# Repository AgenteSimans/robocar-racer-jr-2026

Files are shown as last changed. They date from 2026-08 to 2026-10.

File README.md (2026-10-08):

# 🏎️ Robocar Jr — Placa de Controle & Gerenciamento
### Robocar Race 2025 · hardware em KiCad 10

> Corpo de prova eletrônico de um carro autônomo de competição, projetado no **KiCad** para
> concentrar, em uma única placa, o cérebro (**ESP32‑DEVKITC**), o copiloto embarcado
> (**Raspberry Pi**), os sensores de navegação (**GY‑87**), a medição de energia (**ADS1115**)
> e toda a interface de potência dos atuadores (servo de direção + ESC/motor BLDC).

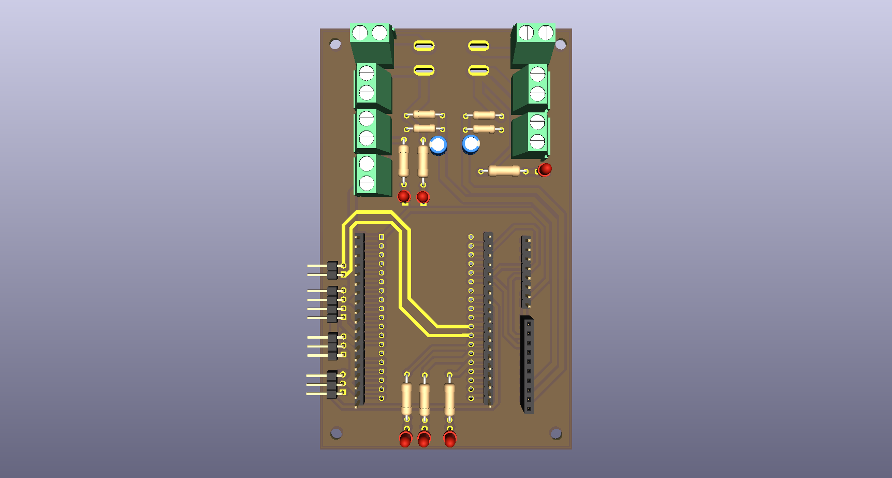
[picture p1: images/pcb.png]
Layout da PCB


<p align="center">
  
  
  
  
  
  
</p>

---

## ✨ O que a placa faz

| Bloco | Papel no veículo |
|---|---|
| 🧠 **ESP32‑DEVKITC** | Controlador em tempo real (sensores, PWM, decisão), montado em soquete. |
| 🍓 **Raspberry Pi** | Co‑processador de visão/navegação, ligado ao ESP32 por **UART** e alimentado via **USB‑C** na placa. |
| 🧭 **GY‑87 (IMU)** | Orientação e movimento — MPU6050 + HMC5883L + BMP280, em barramento I²C. |
| 📊 **ADS1115** | ADC externo de **16 bits** (I²C) com **4 canais** para medição precisa de bateria e dos rails de potência. |
| ⚡ **Gestão de energia** | Conversor **Buck** (+5 V) e conversor **Step‑up** (+8 V / +12 V) a partir da bateria, com chaves de comutação. |
| 🎯 **Atuadores** | Saída dedicada para **servo** (direção, 5 V) e para **ESC/motor BLDC** (tração, 12 V de potência + sinal 5 V). |
| 💡 **Feedback visual** | LEDs de estado (**Estado_1/2/3**) e LEDs de presença de tensão (**+BV**, **+12 V**). |
| 📡 **Enlace serial** | UART `TX/RX_RASPBERRY` para telemetria e troca de comandos ESP32 ↔ Raspberry. |
| 🎮 **Modo manual (opcional)** | Previsão de entradas de receptor RC (`Radio`, `Servo Rec`, `Motor Rec`). |

---

## ⚡ Arquitetura de potência

A bateria (`+BV`) é a fonte primária e é distribuída/comutada por **chaves DPST (SW1/SW2)**.
Dois estágios de conversão DC‑DC geram os rails usados pelo sistema:

| Rail | Gerado por | Alimenta |
|---|---|---|
| **+5 V** (`Buck_out`) | Conversor **Buck** (`Buck_in` → `Buck_out`) | Lógica de sinal, **servo motor**, barramento do enlace |
| **+3,3 V** | Regulação a partir de +5 V | **ESP32**, **GY‑87**, **ADS1115** |
| **+8 V** | Bateria 2S | Alimentação do Motor |
| **+12 V** | Bateria 3S | Alimentação do Esp32 e Raspberry  |
| **USB‑C 5 V** | Conector `Raspbery_usbc` | **Raspberry Pi** |

> O **servo** recebe potência e sinal em 5 V (conector `J3`); o **motor/ESC** recebe a
> potência de 12 V pelo conector `Motor in` (`J11`) e o sinal PWM de 5 V pelo conector `J4` —
> separando claramente o caminho de potência do caminho de controle.

---

## 📊 Monitoramento de bateria e de rails (ADS1115)

Quatro entradas analógicas, todas condicionadas por **divisores resistivos + filtro RC**,
lidas com resolução de 16 bits (muito mais estáveis que o ADC interno do ESP32):

| Canal | Origem medida | Sentido |
|:-----:|---|---|
| **A0** | Divisor de Tensão da Bateria 3S | Tensão da Bateria 3S |
| **A1** | Divisor de Tensão da Bateria 2S | Tensão da Bateria 2S |

Endereço I²C do ADS1115 com `ADDR` amarrado ao GND (**0x48**); `ALERT` usado conforme estratégia de firmware (polling ou interrupção).

---

## 🔗 Comunicação & interfaces

- **I²C (compartilhado):** `SDA` e `SCL` ligam **GY‑87** e **ADS1115** ao ESP32.
- **UART ↔ Raspberry:** pares `TX_RASPBERRY` / `RX_RASPBERRY` formam o enlace serial
  ESP32 ⇄ Raspberry (telemetria, comandos, handshake de missão).
- **Sinais de controle:** `Sinal_Servo` (direção) e `Sinal_Motor` (tração via ESC).
- **Feedback luminoso:** `Estado_1`, `Estado_2`, `Estado_3` (LEDs 3 mm, R = 220 Ω) indicam a
  fase/estado da máquina; LEDs adicionais sinalizam presença de **+BV** (R = 330 Ω) e **+12 V** (R = 1 kΩ).
- **Chaves:** `SW1`/`SW2` (DPST) para comutação/corte dos ramos de bateria e enlace.

---

## 🧱 Conectores de campo

| Ref. | Função | Sinais |
|---|---|---|
| **J7** | Módulo **GY‑87** | +3,3 V · SCL · SDA · GND |
| **J10** | Entrada do **Buck** | `Buck_in` · GND |
| **J11** | Potência do **motor** | +12 V (`Motor in`) · GND |
| **J3** | **Servo motor** | +5 V (`Buck_out`) · `Sinal_Servo` · GND |
| **J4** | Sinal do **ESC/motor** | +5 V · `Sinal_Motor` · GND |
| **J14** | **USB‑C do Raspberry** | +5 V · GND |
| **J15** | Saída do **Step‑up** | +12 V · GND |
| **J2 / J5** | Soquete / breakout **ESP32‑DEVKITC** | barramento completo do módulo |
| **SW1 / SW2** | Chaves DPST | comutação de bateria/enlace |

> A atribuição física de cada GPIO do ESP32 segue o soquete `J2`/`J5`; a referência canônica
> é o esquemático hierárquico incluído no projeto.

---

## 🖼️ Galeria

### Esquemático (hierárquico)
Blocos de baterias, entradas de motor/conversor Buck, barramento do Raspberry, conexões do
GY‑87, enlace serial, ADS1115, divisores de tensão e LEDs de feedback.

Esquemático

### Layout da PCB
Posicionamento dos conectores de bateria e de potência, soquete do ESP32, trilhas de 12 V /
5 V dimensionadas para corrente e separação cuidadosa entre potência e sinal.

PCB

---

## 📄 Licença & crédito

Hardware aberto sob licença **MIT** — use, estude e adapte como base para o seu Robocar Jr. 🏁

<sub>Projeto de competição · **Robocar Race 2025** · desenvolvido por **Pablo Nunes de Oliveira** · KiCad E.D.A. 10</sub>

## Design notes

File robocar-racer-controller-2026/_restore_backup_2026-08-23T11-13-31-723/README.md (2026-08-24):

# robocar-racer-controller-2025

## Visão Geral
Este repositório contém o projeto de hardware da **placa controladora** desenvolvida pela **Equipe Laser** para a competição **Robocar Racer 2025**. A placa recebe e interpreta dados da **Raspberry Pi** para controlar o motor brushless (ESC) e o servo motor, implementando isolamento galvânico e redundância via rádio controle.

---

## Visualização do Projeto

### Modelo 3D
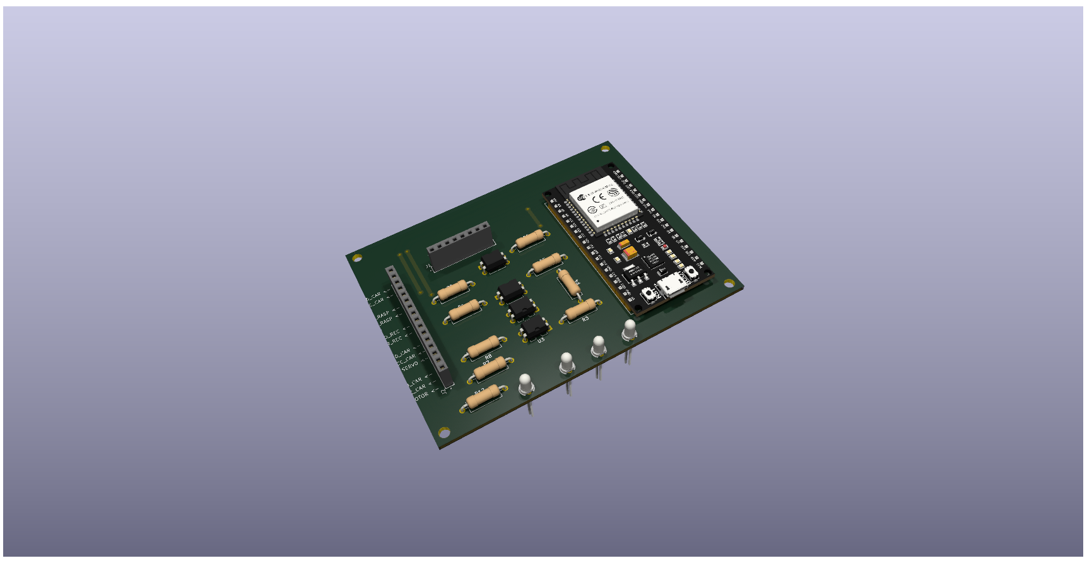
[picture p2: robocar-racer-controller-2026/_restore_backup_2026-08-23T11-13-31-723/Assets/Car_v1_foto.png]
Vista 3D da Controladora


### Documentação Técnica (PDF)
Para detalhes de roteamento e conexões, acesse os arquivos abaixo:
* [📄 Esquemático Completo](Assets/Esquemático.pdf)
* [📄 Layout da PCB](Assets/PCB_layout.pdf)

---

## Especificações Técnicas
* **Microcontrolador:** ESP32 (NodeMCU/DevKit V1)
* **Software de EDA:** KiCad 8.0.6
* **Dimensões da PCB:** 91.00 mm x 67.75 mm
* **Isolamento:** Optoacopladores **PC817** (Separação entre lógica/USB e potência/Bateria).

## Operação e Segurança
O sistema gerencia a tração e direção do veículo em três estados:
1. **Modo Autônomo:** Controle via Raspberry Pi (Serial/USB).
2. **Modo Manual (Radio):** Redundância via rádio controle externo (Fail-safe).
3. **Modo Neutro:** Veículo parado por segurança.

## Interfaces de Hardware
* **Barramento GY-87:** Conexão I2C para IMU (Telemetria e estabilização).
* **Feedback Visual:** 4 LEDs (Power, Estado 1, Estado 2, Estado 3).
* **Isolamento de Terra:** Separação física entre `GND_CAR` e `Earth` (GND lógico).

## Estrutura do Repositório
* **`/Gerber`**: Arquivos finais de fabricação e furação.
* **`/Assets`**: Fotos, modelos 3D e documentação técnica em PDF.
* **`/Meus footprints.pretty`**: Biblioteca de footprints personalizados.
* **`Car_v1.kicad_...`**: Arquivos fonte do projeto para edição no KiCad.

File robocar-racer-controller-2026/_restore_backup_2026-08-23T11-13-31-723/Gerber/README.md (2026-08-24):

# Arquivos de Fabricação (Gerber)

Estes ficheiros são os ativos finais necessários para a produção da PCB, seja via fabricação industrial (JLCPCB, PCBWay, etc.) ou fresagem CNC.

## Especificações para Fabricação

* **Formato:** Gerber RS-274X.
* **Furação:** Excellon Drill Files.
* **Camadas incluídas:**
    * Cobre (Top/Bottom)
    * Máscara de solda (Solder Mask)
    * Legenda/Serigrafia (Silkscreen)
    * Corte de borda (Edge Cuts)

## Instruções

Estes ficheiros foram gerados a partir do KiCad 8.0.6. Se for realizar a fresagem via CNC (ex: utilizando **FlatCAM**), utilize preferencialmente os ficheiros de isolamento gerados para as camadas de cobre.

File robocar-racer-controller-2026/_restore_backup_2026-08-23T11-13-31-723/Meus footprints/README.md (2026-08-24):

# Minha Biblioteca de Footprints Personalizada

Esta pasta contém a minha coleção de footprints desenvolvida para o projeto **Robocar Racer 2025** e outros componentes customizados.

## Sobre a Biblioteca
Esta é uma biblioteca autoral que reúne todos os modelos de componentes que eu desenvolvi ou modifiquei para garantir a precisão do hardware. Optei por incluir a biblioteca completa neste repositório para assegurar que todos os footprints utilizados no layout da PCB estejam disponíveis para consulta e edição.

### Destaques:
* **Módulos Integrados:** Footprints validados para ESP32, sensores e IMUs.
* **Otimização de Soldagem:** Pads ajustados para facilitar a montagem manual e garantir durabilidade.
* **Componentes Customizados:** Modelos criados do zero para componentes que não constam nas bibliotecas padrão do KiCad.

## Uso no Projeto
Para que o KiCad reconheça as peças corretamente ao abrir o arquivo `.kicad_pcb`:
1. Vá em **Preferences** > **Manage Footprint Libraries**.
2. Na aba **Project Specific Libraries**, adicione esta pasta (`Meus footprints.pretty`).

**Nota:** Por ser uma biblioteca completa, ela pode conter componentes adicionais que não estão em uso nesta versão específica da placa, mas que fazem parte do meu fluxo de design.

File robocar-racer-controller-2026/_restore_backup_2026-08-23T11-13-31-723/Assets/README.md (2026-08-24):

# Assets do Projeto

Esta pasta contém os recursos visuais e a documentação técnica exportada para consulta rápida.

## Conteúdo

* **Imagens:**
    * `Car_v1_foto_da_PCB.png`: Renderização 3D da placa para visualização de componentes.
* **Documentação (PDF):**
    * `Esquemático.pdf`: Diagrama elétrico completo do sistema.
    * `PCB_layout.pdf`: Desenho das trilhas, planos de terra e camadas de montagem.

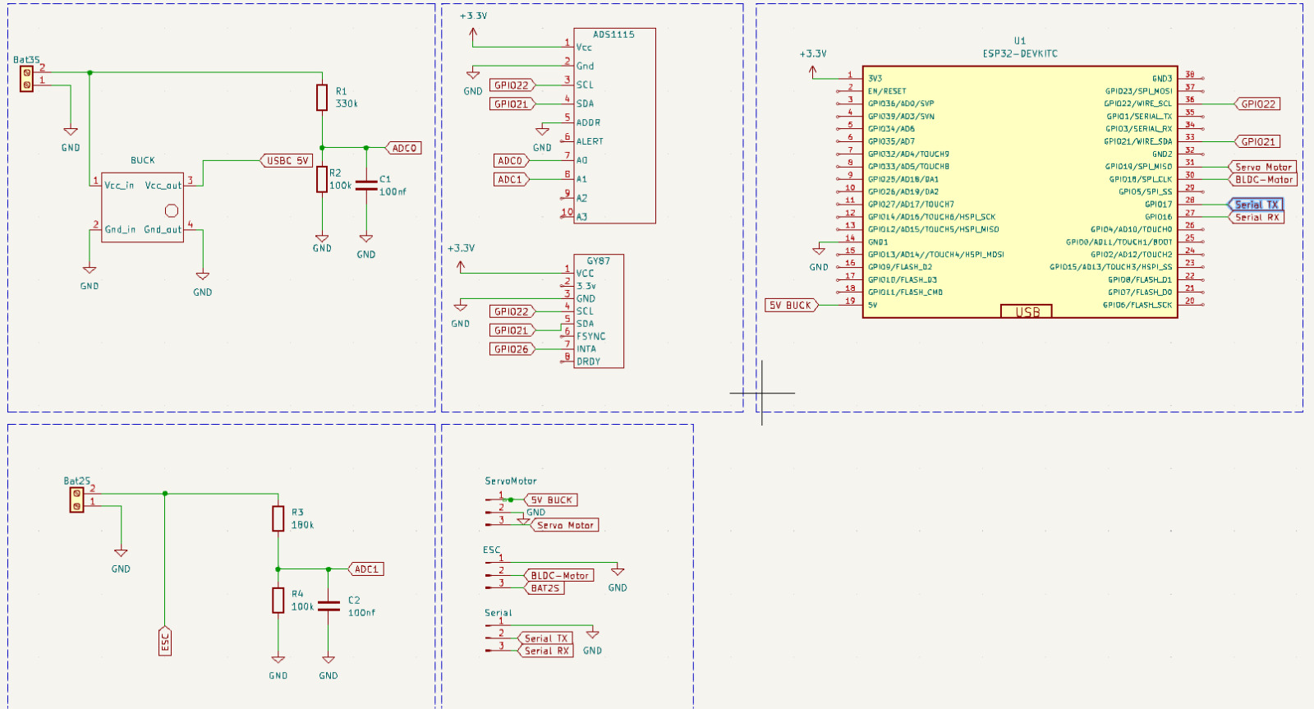
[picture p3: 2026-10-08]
images/esquematico.jpeg

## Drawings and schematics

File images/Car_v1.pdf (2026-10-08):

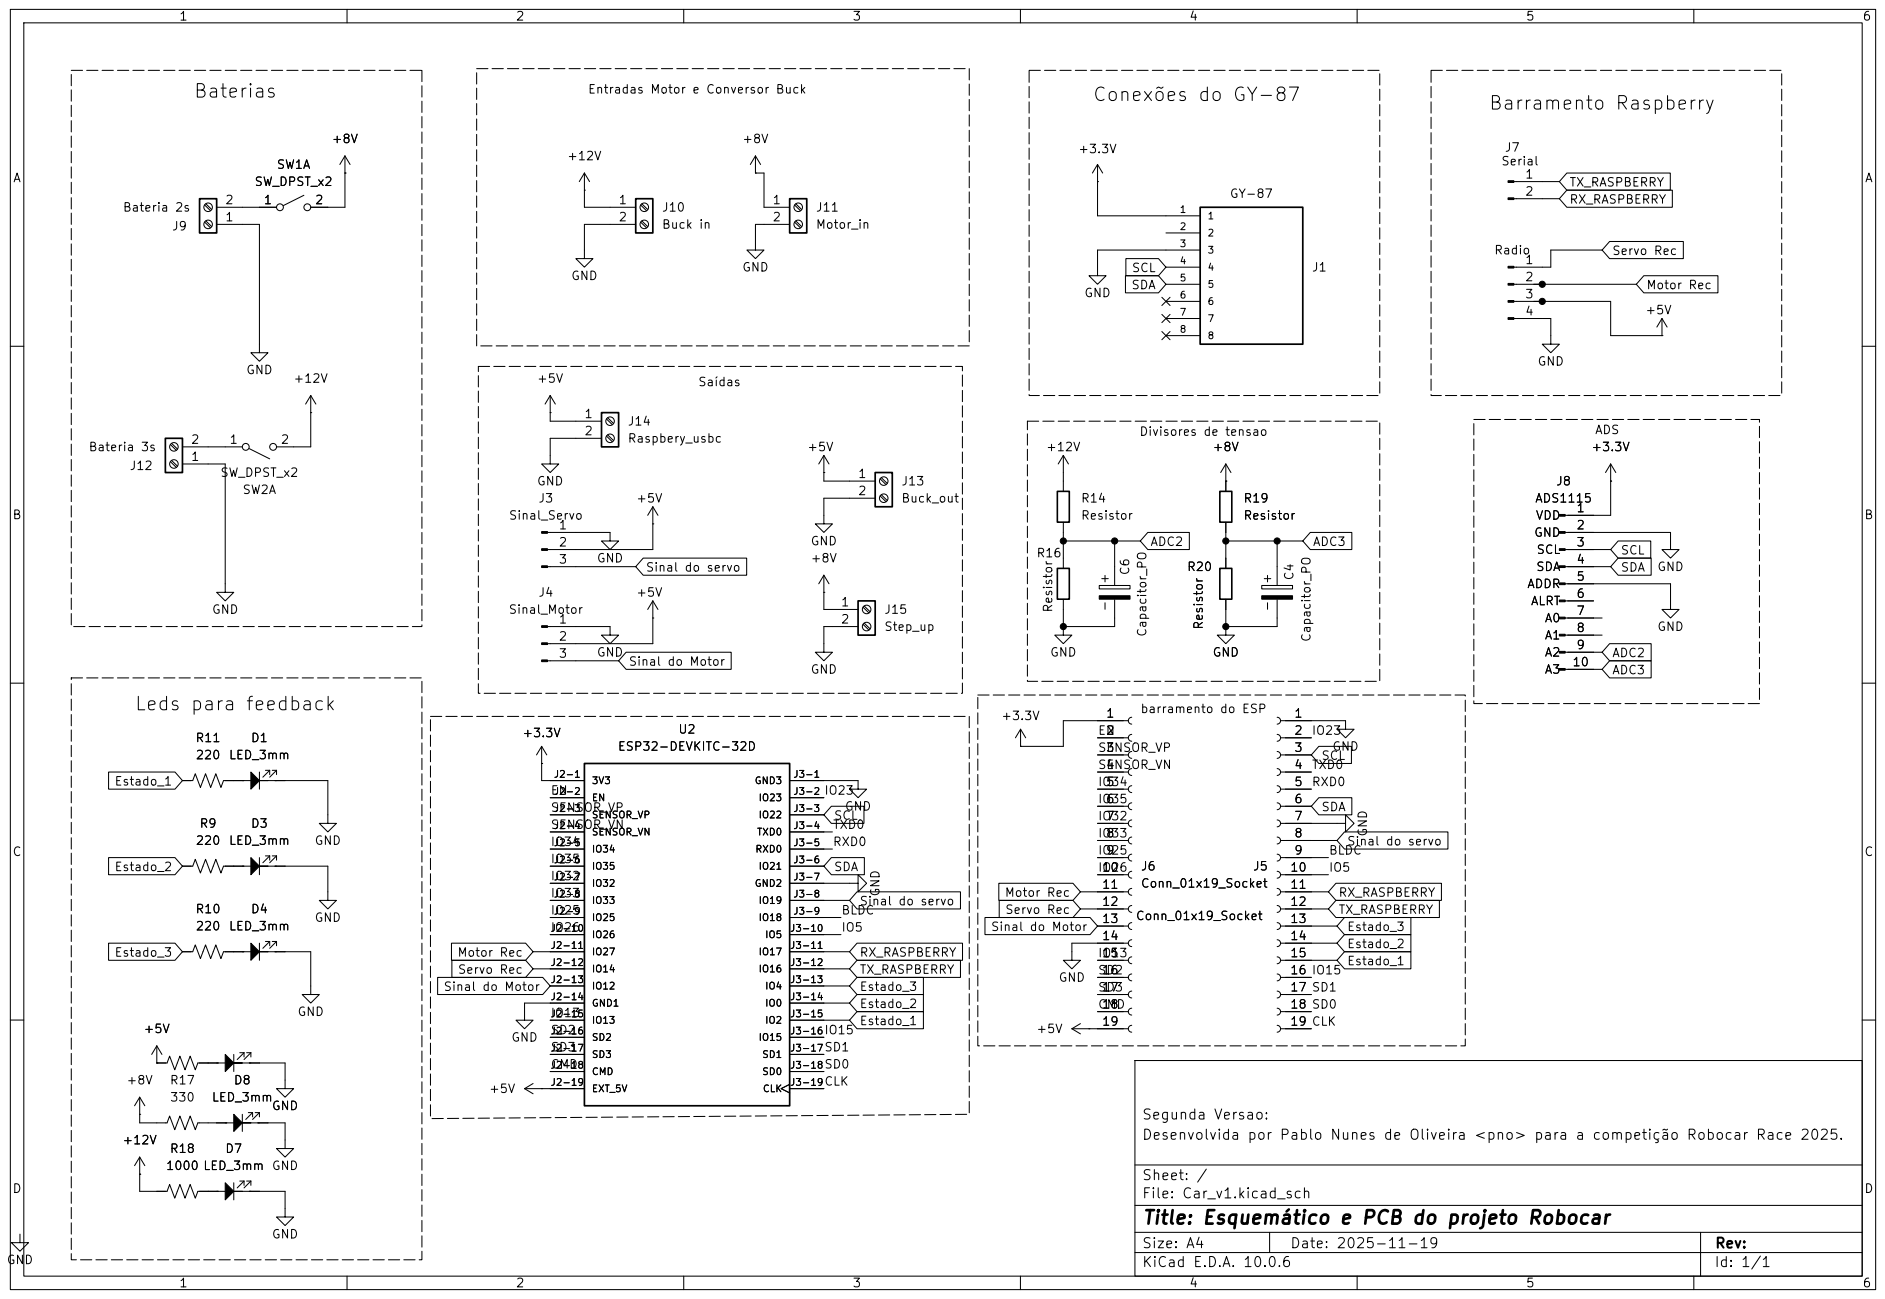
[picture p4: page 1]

Saídas Entradas Motor e Conversor Buck U2

Segunda Versao:
Desenvolvida por Pablo Nunes de Oliveira <pno> para a competição Robocar Race 2025.

Sheet: /
File: Car_v1.kicad_sch
Title: Esquemático e PCB do projeto Robocar

Size: A4 | Rev:
KiCad E.D.A. 10.0.6 | Id: 1/1

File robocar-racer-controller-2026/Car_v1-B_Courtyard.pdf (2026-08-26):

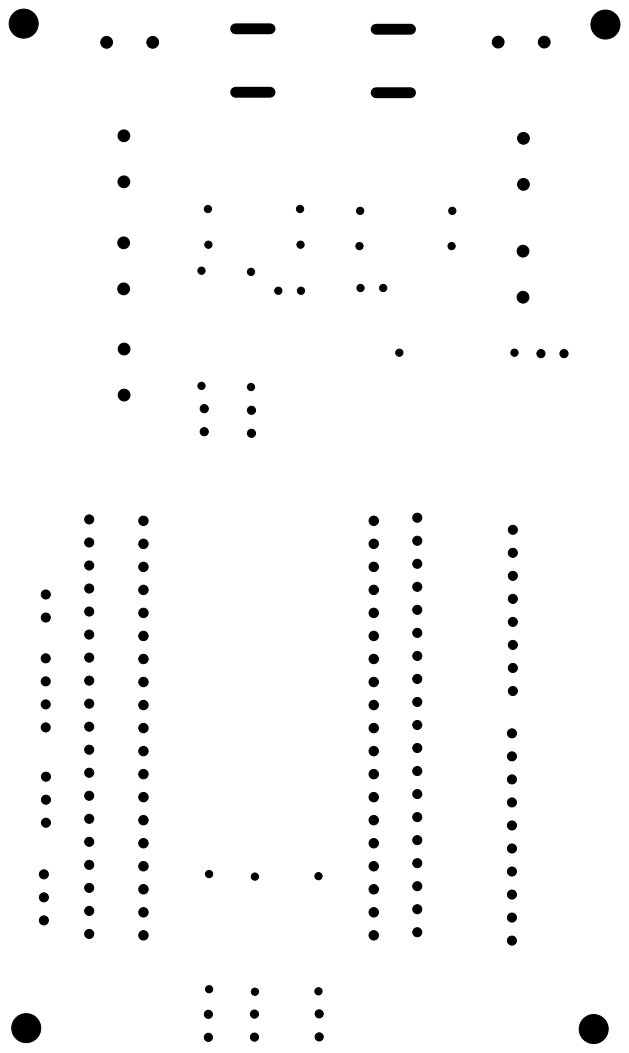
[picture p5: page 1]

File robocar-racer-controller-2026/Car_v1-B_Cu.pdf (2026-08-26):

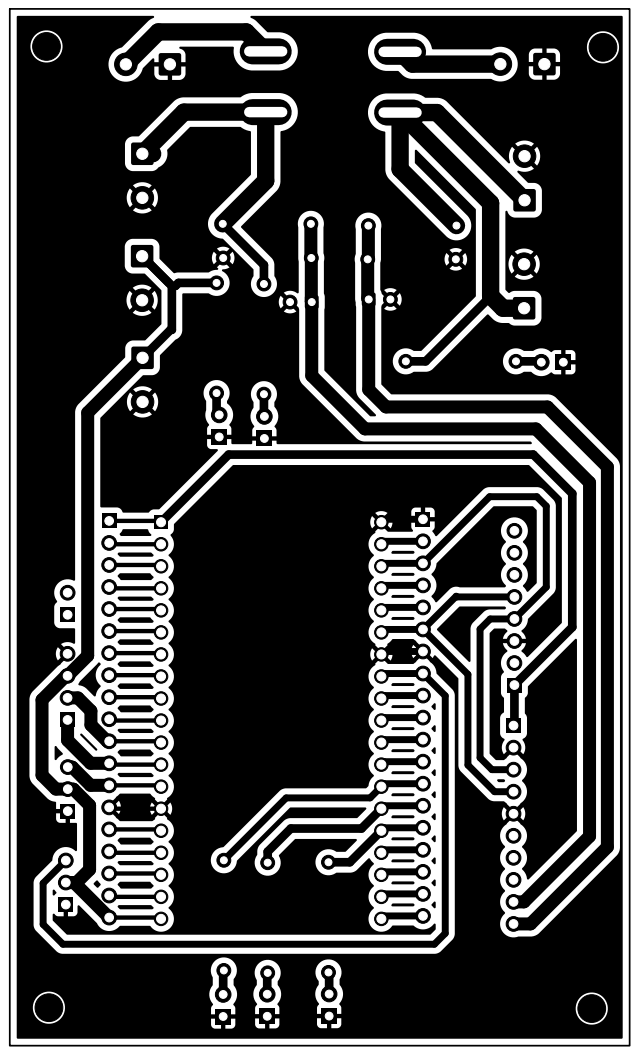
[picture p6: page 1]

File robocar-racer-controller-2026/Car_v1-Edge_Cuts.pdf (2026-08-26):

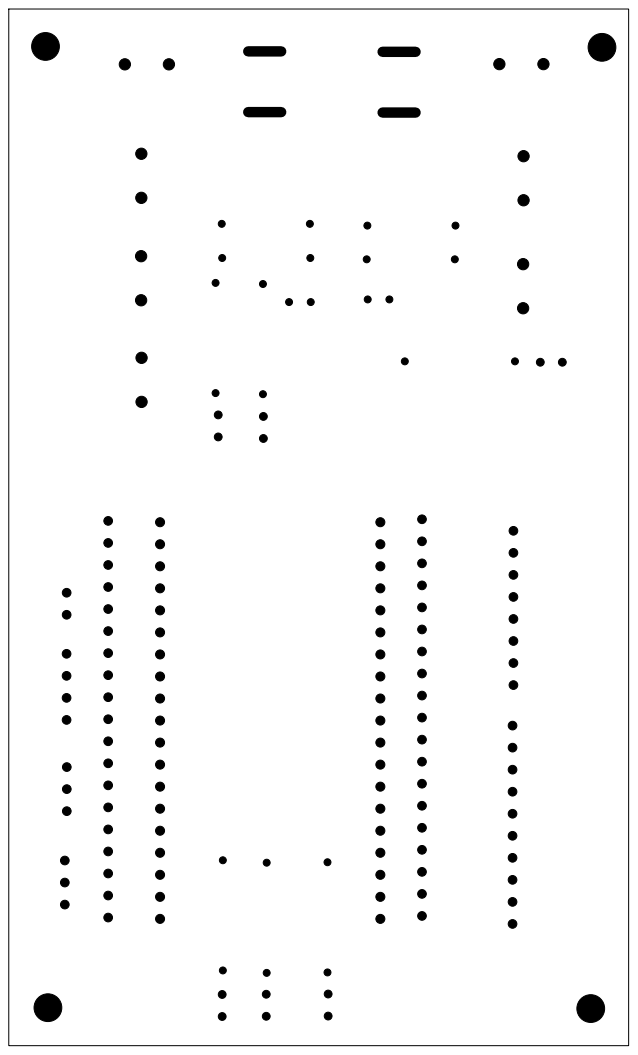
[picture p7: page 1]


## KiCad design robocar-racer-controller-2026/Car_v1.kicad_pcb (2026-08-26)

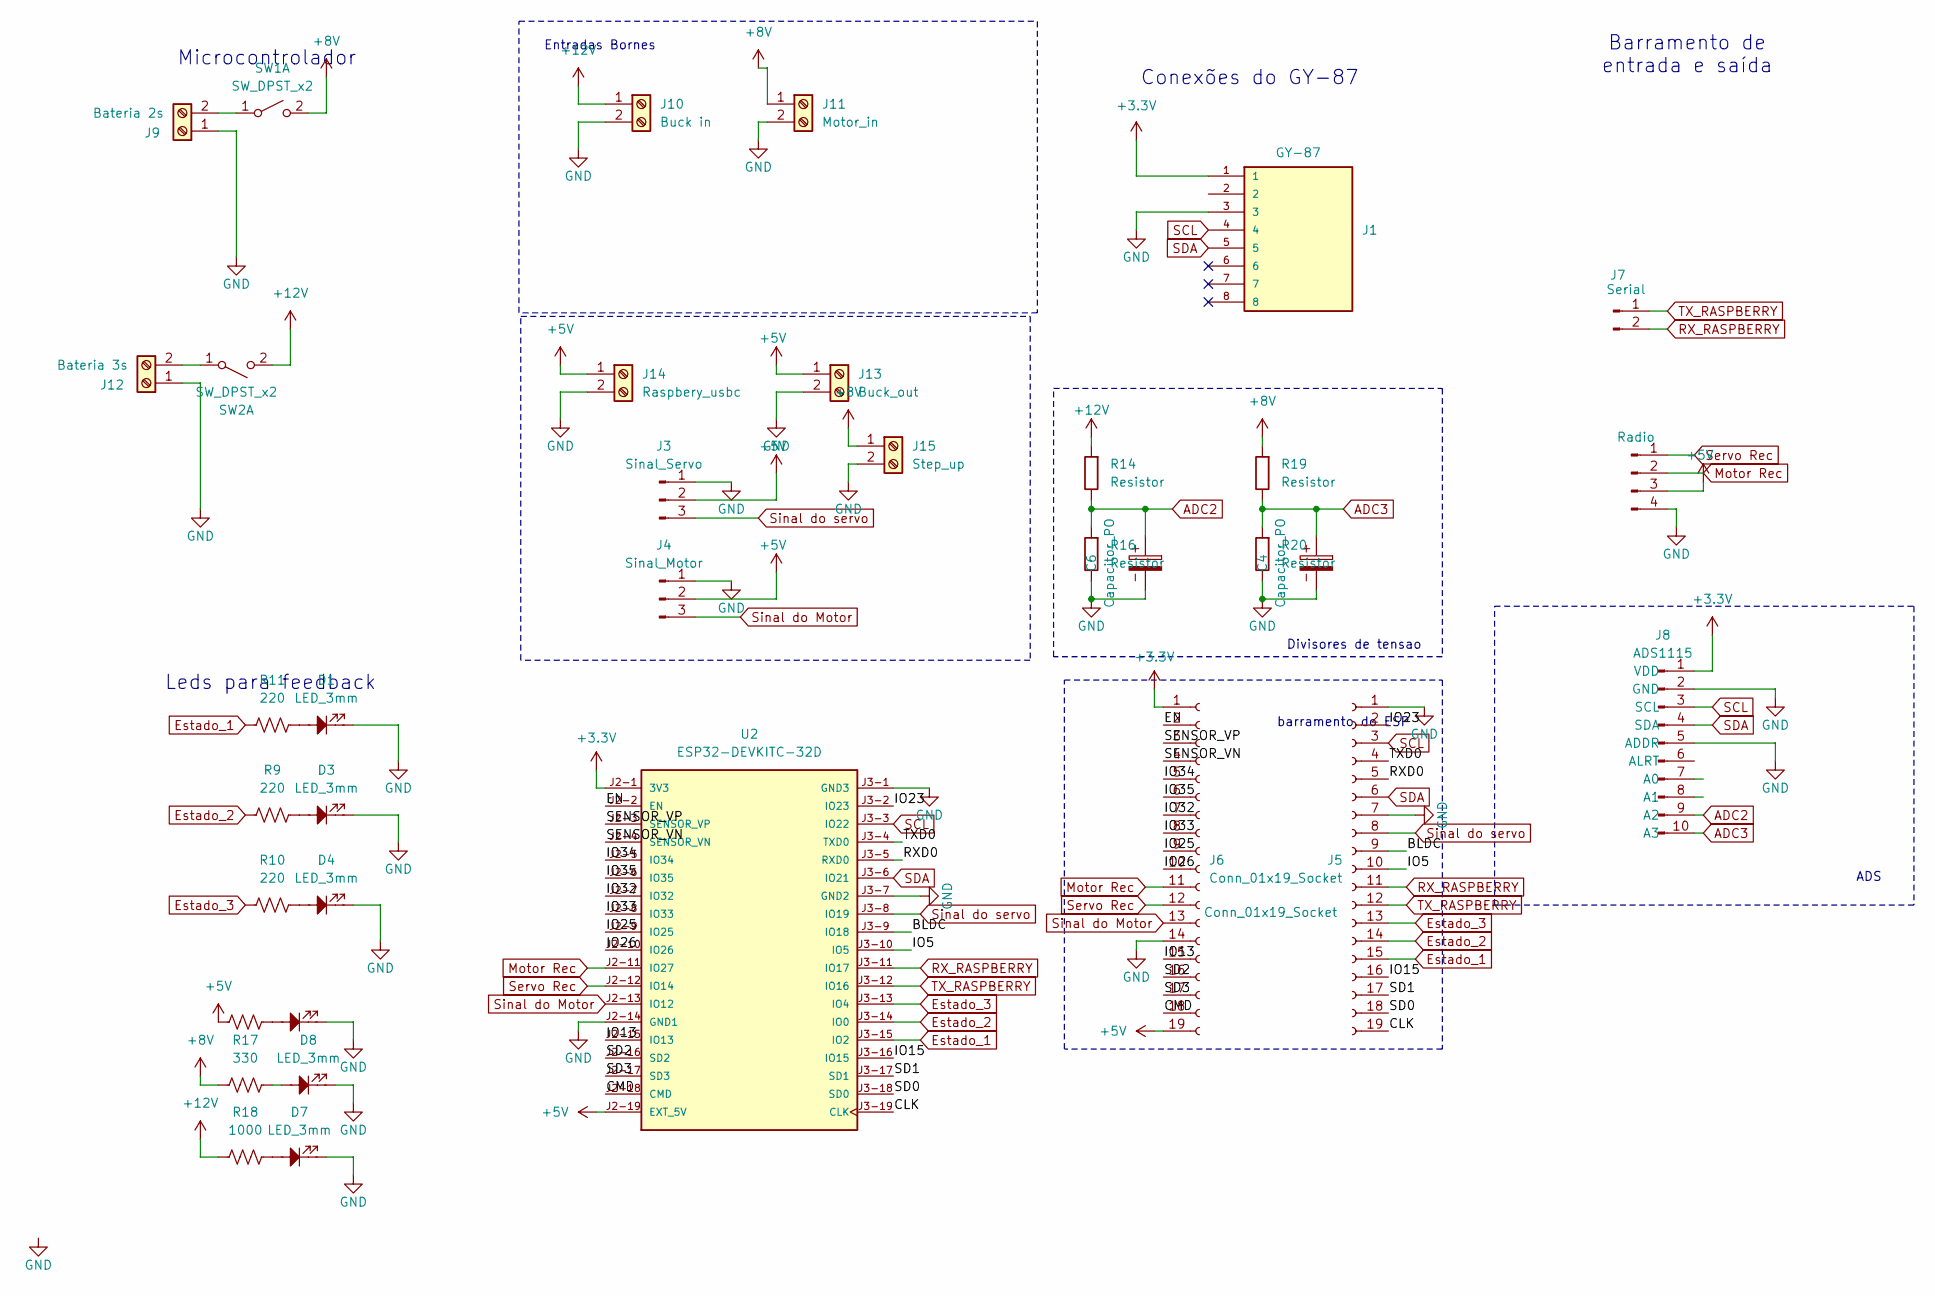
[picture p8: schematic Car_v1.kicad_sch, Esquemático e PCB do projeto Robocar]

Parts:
C4, C6: Capacitor_PO; CP_Radial_D5.0mm_P2.50mm
D1, D3, D4, D5, D7, D8: LED_3mm; LED_D3.0mm
J1: GY-87; Pins_1x08_2.54mm_TH; PARTREV R
J3: Sinal_Servo; PinHeader_1x03_P2.54mm_Horizontal
J4: Sinal_Motor; PinHeader_1x03_P2.54mm_Horizontal
J5, J6: Conn_01x19_Socket; PinHeader_1x19_P2.54mm_Vertical
J7: Serial; PinHeader_1x02_P2.54mm_Horizontal
J8: ADS1115; PinSocket_1x10_P2.54mm_Vertical
J9: Bateria 2s; TerminalBlock_Phoenix_MKDS-1,5-2-5.08_1x02_P5.08mm_Horizont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
J10: Buck in; TerminalBlock_Phoenix_MKDS-1,5-2-5.08_1x02_P5.08mm_Horizont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
J11: Motor_in; TerminalBlock_Phoenix_MKDS-1,5-2-5.08_1x02_P5.08mm_Horizont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
J12: Bateria 3s; TerminalBlock_Phoenix_MKDS-1,5-2-5.08_1x02_P5.08mm_Horizont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
J13: Buck_out; TerminalBlock_Phoenix_MKDS-1,5-2-5.08_1x02_P5.08mm_Horizont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
J14: Raspbery_usbc; TerminalBlock_Phoenix_MKDS-1,5-2-5.08_1x02_P5.08mm_Horizont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
J15: Step_up; TerminalBlock_Phoenix_MKDS-1,5-2-5.08_1x02_P5.08mm_Horizont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
J16: Radio; PinHeader_1x04_P2.54mm_Horizontal
R9, R10, R11, R12: 220; R_Axial_DIN0309_L9.0mm_D3.2mm_P12.70mm_Horizontal
R14, R16, R19, R20: Resistor; R_Axial_DIN0207_L6.3mm_D2.5mm_P10.16mm_Horizontal
R17: 330; R_Axial_DIN0309_L9.0mm_D3.2mm_P12.70mm_Horizontal
R18: 1000; R_Axial_DIN0309_L9.0mm_D3.2mm_P12.70mm_Horizontal
SW1, SW2: SW_DPST_x2; KCD1
U2: ESP32-DEVKITC-32D; MODULE_ESP32-DEVKITC-32D; PARTREV V4

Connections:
+3.3V: J1.1, J6.1, J8.1 (VDD), U2.J2-1 (3V3)
+5V: J3.2, J4.2, J6.19, J13.1, J14.1, J16.3, R12.1, U2.J2-19 (EXT_5V)
+8V: J11.1, J15.1, R17.1, R19.1, SW1.2 (B)
+12V: J10.1, R14.1, R18.1, SW2.2 (B)
/BLDC: J5.9, U2.J3-9 (IO18)
/CLK: J5.19, U2.J3-19 (CLK)
/CMD: J6.18, U2.J2-18 (CMD)
/EN: J6.2, U2.J2-2 (EN)
/IO5: J5.10, U2.J3-10 (IO5)
/IO13: J6.15, U2.J2-15 (IO13)
/IO15: J5.16, U2.J3-16 (IO15)
/IO23: J5.2, U2.J3-2 (IO23)
/IO25: J6.9, U2.J2-9 (IO25)
/IO26: J6.10, U2.J2-10 (IO26)
/IO32: J6.7, U2.J2-7 (IO32)
/IO33: J6.8, U2.J2-8 (IO33)
/IO34: J6.5, U2.J2-5 (IO34)
/IO35: J6.6, U2.J2-6 (IO35)
/RXD0: J5.5, U2.J3-5 (RXD0)
/SD0: J5.18, U2.J3-18 (SD0)
/SD1: J5.17, U2.J3-17 (SD1)
/SD2: J6.16, U2.J2-16 (SD2)
/SD3: J6.17, U2.J2-17 (SD3)
/SENSOR_VN: J6.4, U2.J2-4 (SENSOR_VN)
/SENSOR_VP: J6.3, U2.J2-3 (SENSOR_VP)
/TXD0: J5.4, U2.J3-4 (TXD0)
ADC2: C6.1, J8.9 (A2), R14.2, R16.1
ADC3: C4.1, J8.10 (A3), R19.2, R20.1
Estado_1: J5.15, R11.1, U2.J3-15 (IO2)
Estado_2: J5.14, R9.1, U2.J3-14 (IO0)
Estado_3: J5.13, R10.1, U2.J3-13 (IO4)
GND: C4.2, C6.2, D1.1, D3.1, D4.1, D5.1, D7.1, D8.1, J1.3, J3.1, J4.1, J5.1, J5.7, J6.14, J8.2 (GND), J8.5 (ADDR), J9.1, J10.2, J11.2, J12.1, J13.2, J14.2, J15.2, J16.4, R16.2, R20.2, U2.J2-14 (GND1), U2.J3-1 (GND3), U2.J3-7 (GND2)
Motor Rec: J6.11, J16.2, U2.J2-11 (IO27)
unnamed: D1.2, R11.2
unnamed: D3.2, R9.2
unnamed: D4.2, R10.2
unnamed: D5.2, R12.2
unnamed: D7.2, R18.2
unnamed: D8.2, R17.2
unnamed: J9.2, SW1.1 (A)
unnamed: J12.2, SW2.1 (A)
RX_RASPBERRY: J5.11, J7.2, U2.J3-11 (IO17)
SCL: J1.4, J5.3, J8.3 (SCL), U2.J3-3 (IO22)
SDA: J1.5, J5.6, J8.4 (SDA), U2.J3-6 (IO21)
Servo Rec: J6.12, J16.1, U2.J2-12 (IO14)
Sinal do Motor: J4.3, J6.13, U2.J2-13 (IO12)
Sinal do servo: J3.3, J5.8, U2.J3-8 (IO19)
TX_RASPBERRY: J5.12, J7.1, U2.J3-12 (IO16)

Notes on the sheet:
Conexões do GY-87
Barramento de entrada e saída
barramento do ESP
Divisores de tensao
Entradas Bornes
Leds para feedback
Microcontrolador
ADS

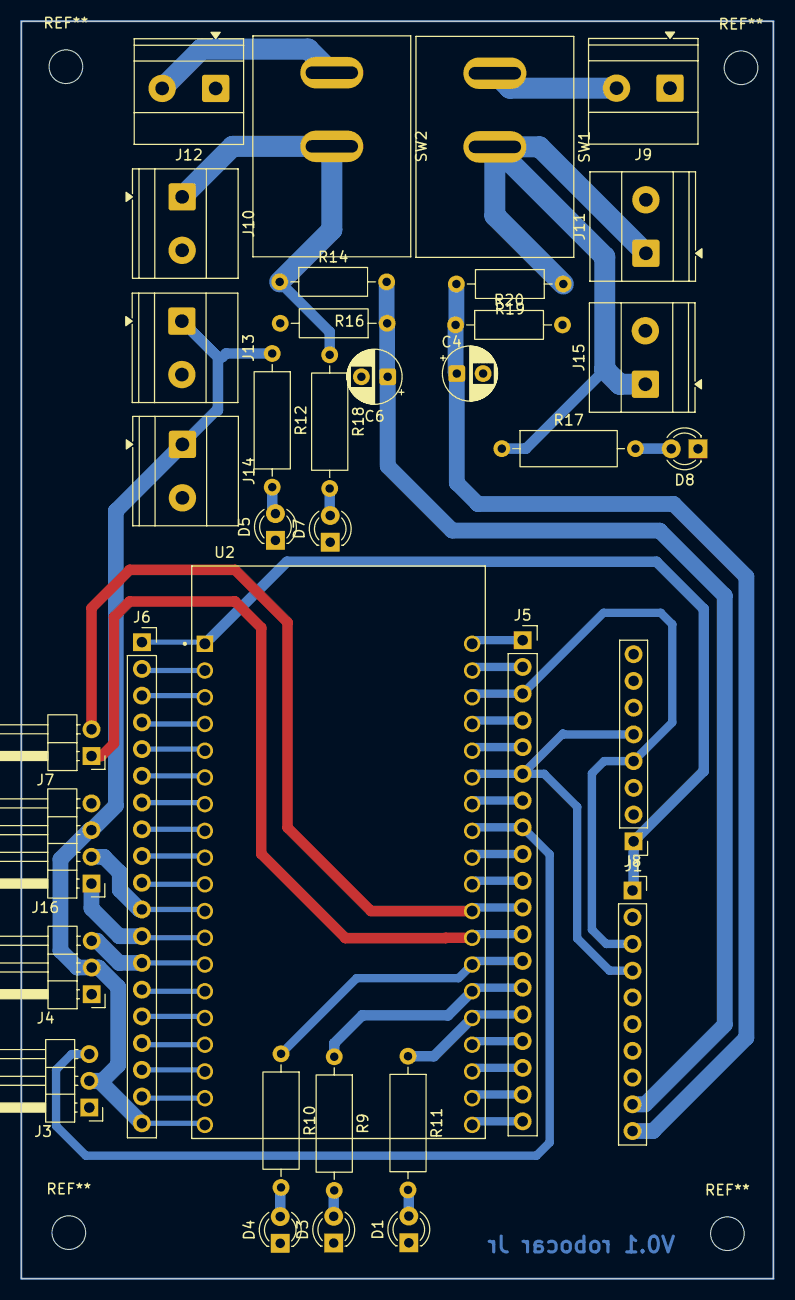
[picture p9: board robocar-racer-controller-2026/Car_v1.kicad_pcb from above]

Board: 2 copper layers, 71.5 x 119.5 mm, 36 parts (0 on the bottom side), 48 nets.

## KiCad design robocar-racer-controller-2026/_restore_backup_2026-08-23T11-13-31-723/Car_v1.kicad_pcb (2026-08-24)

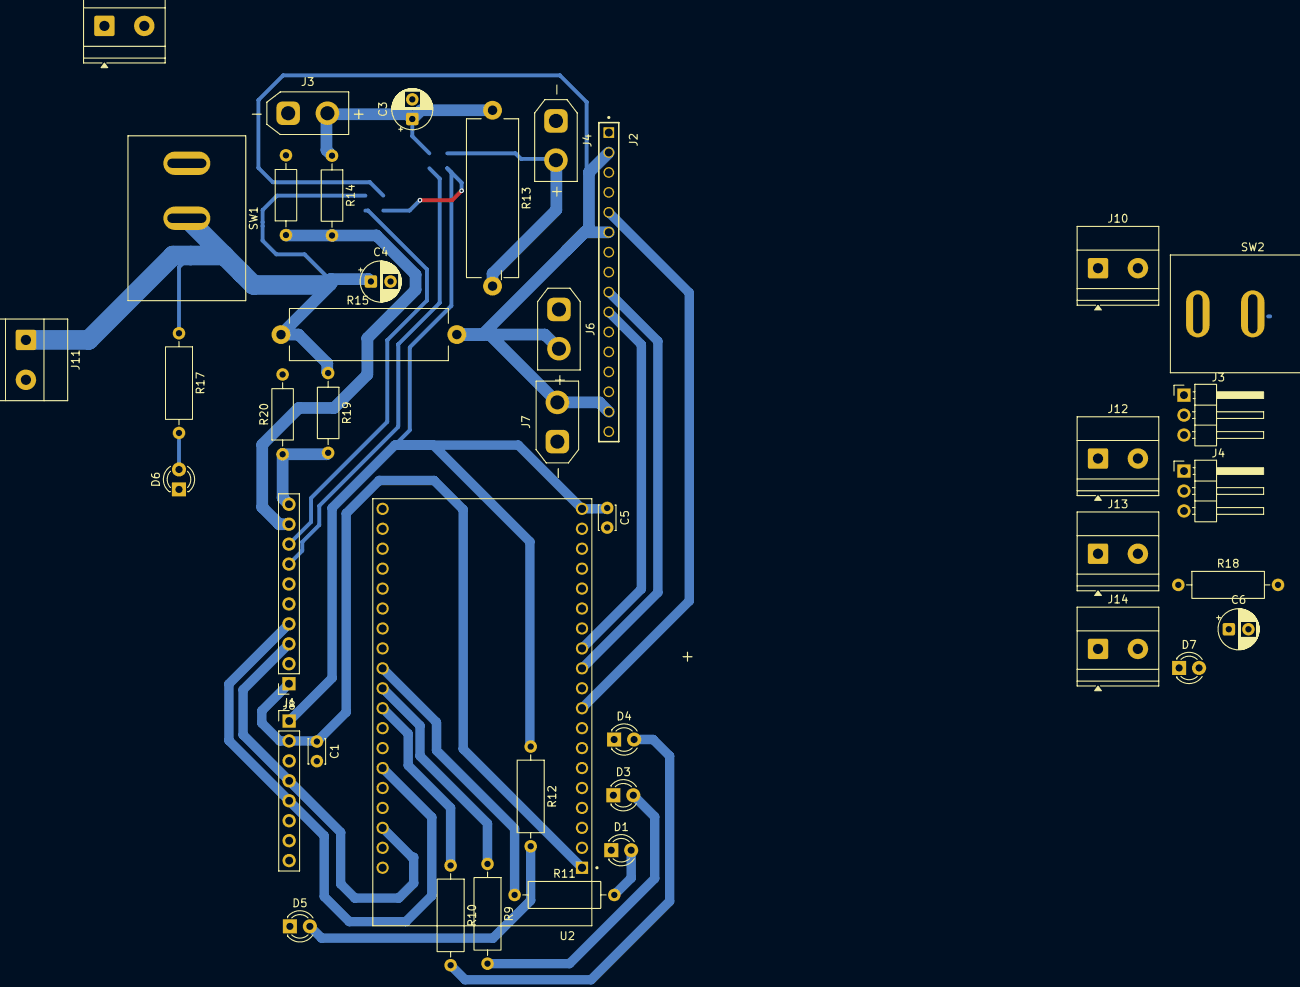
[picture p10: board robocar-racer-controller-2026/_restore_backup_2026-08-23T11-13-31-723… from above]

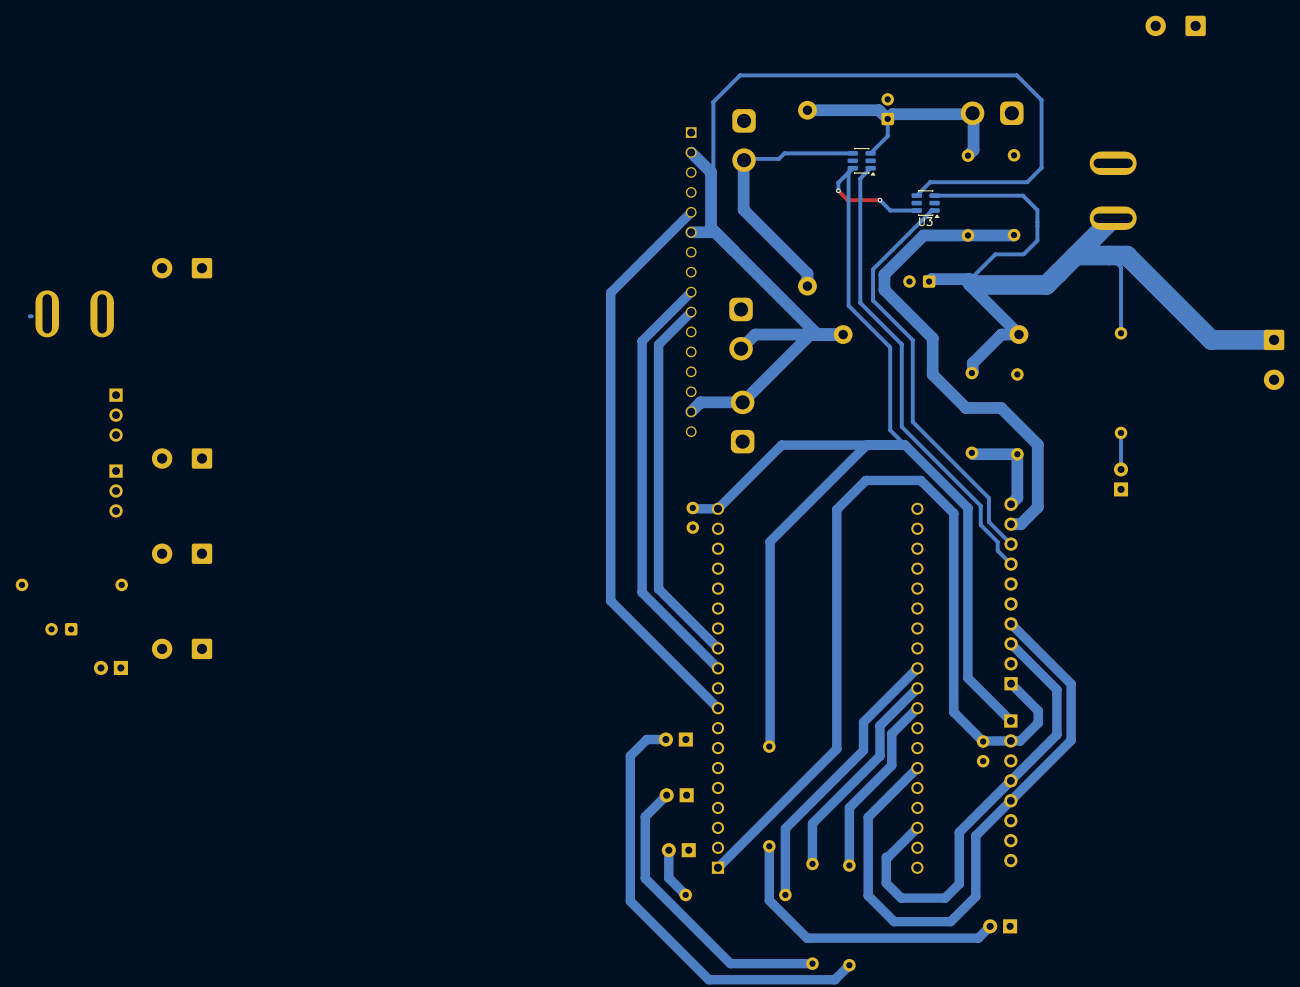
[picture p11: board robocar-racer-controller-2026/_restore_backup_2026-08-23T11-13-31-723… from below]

Board: 2 copper layers, 43 parts (2 on the bottom side), 30 nets.

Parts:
C1: 0.1uF; C_Disc_D3.0mm_W2.0mm_P2.50mm
C3, C4, C6: Capacitor_PO; CP_Radial_D5.0mm_P2.50mm
C5: 100mF; C_Disc_D3.0mm_W2.0mm_P2.50mm
D1, D3, D4, D5, D6, D7: LED_3mm; LED_D3.0mm
J1: GY-87; Pins_1x08_2.54mm_TH
J2: Barramento 16 pinos; SAMTEC_TSW-116-22-T-S
J3, J4#2: Conn_01x03_Pin; PinHeader_1x03_P2.54mm_Horizontal
J3#2: Bateria 3s; AMASS_XT30UPB-F_1x02_P5.0mm_Vertical
J4: Buck 5v; AMASS_XT30UPB-F_1x02_P5.0mm_Vertical
J6: Stepup; AMASS_XT30UPB-F_1x02_P5.0mm_Vertical
J7: ESC; AMASS_XT30UPB-F_1x02_P5.0mm_Vertical
J8: ADS1115; PinSocket_1x10_P2.54mm_Vertical
J9: Bateria 2s; TerminalBlock_Phoenix_MKDS-1,5-2-5.08_1x02_P5.08mm_Horizont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
J10: Buck in; TerminalBlock_Phoenix_MKDS-1,5-2-5.08_1x02_P5.08mm_Horizont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
J11: Motor_in; TerminalBlock_Phoenix_MKDS-1,5-2-5.08_1x02_P5.08mm_Horizont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
J12: Bateria 3s; TerminalBlock_Phoenix_MKDS-1,5-2-5.08_1x02_P5.08mm_Horizont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
J13: Buck_out; TerminalBlock_Phoenix_MKDS-1,5-2-5.08_1x02_P5.08mm_Horizont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
J14: Raspbery_usbc; TerminalBlock_Phoenix_MKDS-1,5-2-5.08_1x02_P5.08mm_Horizont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
R9, R10, R11, R12: 220; R_Axial_DIN0309_L9.0mm_D3.2mm_P12.70mm_Horizontal
R13, R15: Shunt; R_Axial_Power_L20.0mm_W6.4mm_P22.40mm
R14, R16, R19, R20: Resistor; R_Axial_DIN0207_L6.3mm_D2.5mm_P10.16mm_Horizontal
R17: 330; R_Axial_DIN0309_L9.0mm_D3.2mm_P12.70mm_Horizontal
R18: 1000; R_Axial_DIN0309_L9.0mm_D3.2mm_P12.70mm_Horizontal
SW1, SW2: SW_DPST_x2; KCD1
U1, U3: INA181; SOT-23-6
U2: ESP32-DEVKITC-32D; MODULE_ESP32-DEVKITC-32D

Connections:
5V: C5.1, R12.1, U1.6 (V+), U2.J2-19 (EXT_5V), U3.6 (V+)
12V: C3.1, J3#2.2, R13.1, U1.3 (+)
+3.3V: C1.1, J1.1, J8.1 (VDD), U2.J2-1 (3V3)
+5V: J3.2, J4#2.2, J13.1, J14.1
+8V: C4.1, J11.1, R15.1, R17.1, R19.1, SW1.2 (B), U3.3 (+)
+12V: C6.1, J10.1, R14.1, R18.1, SW2.2 (B)
ADC0: J8.7 (A0), U1.1
ADC1: J8.8 (A1), U3.1
ADC2: J8.9 (A2), R14.2, R16.1
ADC3: J8.10 (A3), R19.2, R20.1
Estado_1: R11.1, U2.J3-11 (IO17)
Estado_2: R9.1, U2.J3-10 (IO5)
Estado_3: R10.1, U2.J3-9 (IO18)
GND: C1.2, C3.2, C4.2, C5.2, C6.2, D1.1, D3.1, D4.1, D5.1, D6.1, D7.1, J1.3, J2.03, J2.07, J2.16, J3.1, J3#2.1, J4.1, J4#2.1, J6.1, J7.1, J8.2 (GND), J8.5 (ADDR), J9.1, J10.2, J11.2, J12.1, J13.2, J14.2, R16.2, R20.2, U1.2 (GND), U1.5 (REF), U2.J2-14 (GND1), U2.J3-1 (GND3), U2.J3-7 (GND2), U3.2 (GND), U3.5 (REF)
Motor Rec: J2.09, U2.J2-11 (IO27)
unnamed: D1.2, R11.2
unnamed: D3.2, R9.2
unnamed: D4.2, R10.2
unnamed: D5.2, R12.2
unnamed: D6.2, R17.2
unnamed: D7.2, R18.2
unnamed: J4.2, R13.2, U1.4 (-)
unnamed: J9.2, SW1.1 (A)
unnamed: J12.2, SW2.1 (A)
SCL: J1.4, J8.3 (SCL), U2.J3-3 (IO22)
SDA: J1.5, J8.4 (SDA), U2.J3-6 (IO21)
Servo Rec: J2.10, U2.J2-12 (IO14)
Sinal do Motor: J4#2.3, U2.J2-13 (IO12)
Sinal do servo: J2.05, J3.3, U2.J2-9 (IO25)
VCC_CAR: J2.02, J2.06, J2.15, J6.2, J7.2, R15.2, U3.4 (-)

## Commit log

2026-08-24 atualizado e reduzido
    [Car_v1.kicad_pcb, Car_v1.kicad_sch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]
2026-08-26 organizando o esquematico
    [Car_v1.kicad_pcb, Car_v1.kicad_sch]
2026-08-26 ajustes na entrada serial
    [Car_v1.kicad_pcb, Car_v1.kicad_sch]
2026-10-08 Change schematic image from PNG to JPEG
    Updated schematic image format from PNG to JPEG.
2026-10-08 Revise README for Robocar Jr project details
    Updated the README to reflect changes in the Robocar Jr project, including detailed descriptions of components and their roles, as well as modifications to the power architecture and monitoring secti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
2026-10-08 Update schematic image format from PDF to SVG
2026-10-08 Update voltage measurement descriptions in README
2026-10-08 Update power supply information in README
2026-11-06 ajustes nas vias, adicao de switch e preparacao pra segunda confeccao
2026-11-06 ajustes para fabricacao
2026-11-07 adicao de coneccao do inta do giroscopio
